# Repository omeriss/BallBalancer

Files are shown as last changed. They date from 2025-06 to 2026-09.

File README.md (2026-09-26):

# Ball-Balancing Platform Firmware

Firmware for an STM32H5 that balances a ball on a tiltable
platform, it is written entirely in C using the native STM32 Ecosystem. A resistive touchscreen is used to sensethe ball's position, a PID
loop turns the position error into a desired platform tilt, an RRS3
parallel-manipulator inverse-kinematics model converts that tilt into three
motor angles, and three stepper motors drive the platform.

## How it works

The main loop in [Core/Src/main.c](Core/Src/main.c) ties everything together:

1. **Sense** — I reads the ball's (x, y) position off
   the resistive touchscreen. Each axis is read by driving one pair of GPIOs
   and sampling the opposing pair through `ADC1`, swapping roles between the
   X and Y axes. Touch calibration is persisted to flash.
2. **Control** — I run the PID controller per axis, in order to get the new desired position.
3. **Inverse kinematics** — [inverse_kinematics.c](User/Src/inverse_kinematics.c)
   solves the RRS3 (Revolute-Revolute-Spherical, 3-leg) parallel manipulator
   geometry, turning a desired platform height + tilt into each
   leg's motor angle.
4. **Actuate** — [stepper.c](User/Src/stepper.c) drives each leg's stepper
   motor via step/direction GPIOs.

Peripheral init (clocks, GPIO, ADC1, TIM1, I2C1) is generated by STM32CubeMX
from [h52.ioc](h52.ioc) into `Core/` and `cmake/stm32cubemx/`. All
application logic lives in `User/Src` / `User/Inc`, wired
together from the `USER CODE` sections of `Core/Src/main.c`.

## Repository layout

```
Core/                  CubeMX-generated HAL init + main.c (USER CODE sections only are hand-edited)
Drivers/               STM32H5 HAL + CMSIS (vendored)
User/Src, User/Inc/    Application logic: screen, pid, inverse_kinematics, stepper, utils
cmake/                 Toolchain file + generated stm32cubemx CMake target
tests/                 Host-side unit tests for inverse_kinematics.c
h52.ioc                CubeMX project file
```

## Parts List

- STM32H503CBT6 microcontroller
- 3x NEMA 16 stepper motors
- 3x TMC2208 stepper drivers
- 8V-100V to 3.3V voltage regulator
- 15V power supply
- 3x 100uF capacitors
- 3x 26mm tie rods
- M3 screws (6x 22mm, 12x 12mm, 5x 10mm)
- Proto PCBs and wires / custom PCB
- 3D printed parts

## Images

<p float="left">
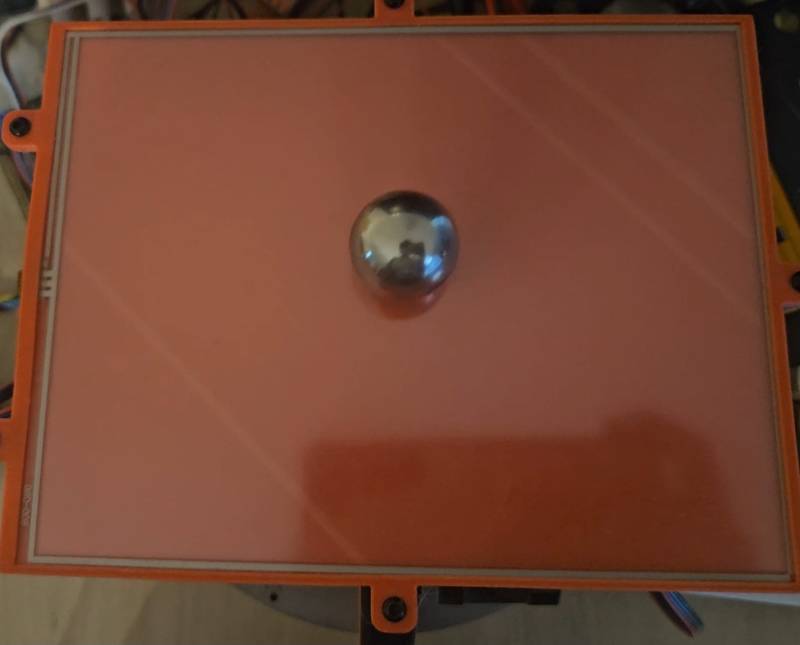
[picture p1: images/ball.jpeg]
Ball
  
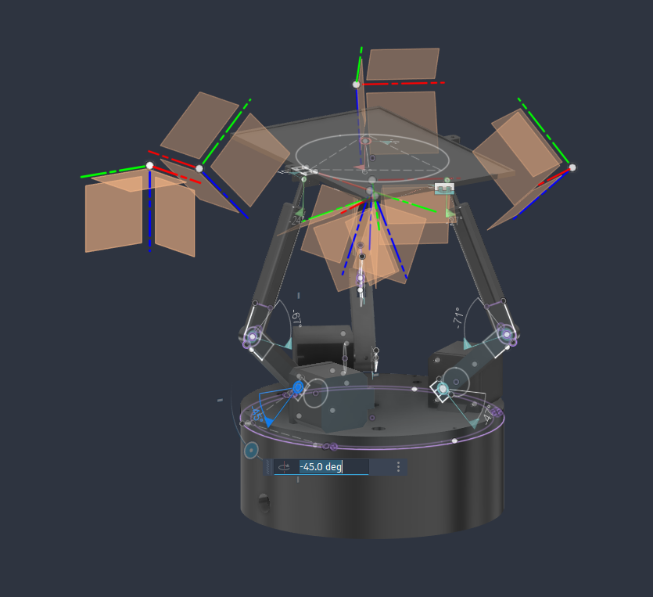
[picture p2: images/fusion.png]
Fusion 360 design
  
</p>

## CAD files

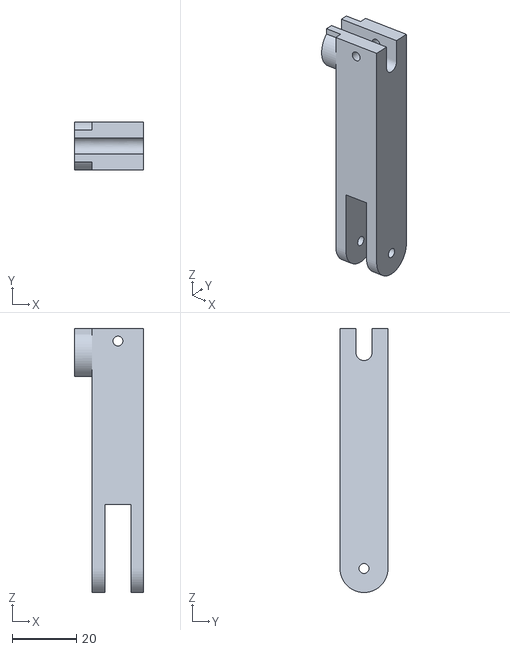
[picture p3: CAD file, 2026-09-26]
3dFiles/leg_buttom.stl
21.7 x 15.0 x 82.5

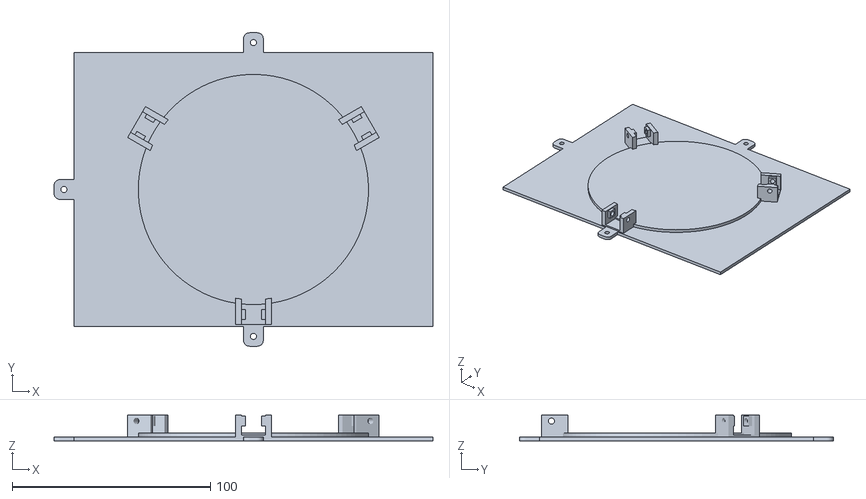
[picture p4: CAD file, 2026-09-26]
3dFiles/screen_bed_buttom.stl
191.0 x 158.0 x 13.0

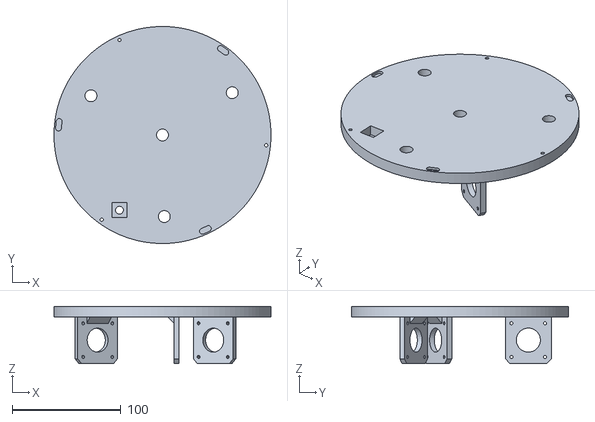
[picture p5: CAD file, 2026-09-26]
3dFiles/base_lid.stl
200.0 x 200.0 x 52.9

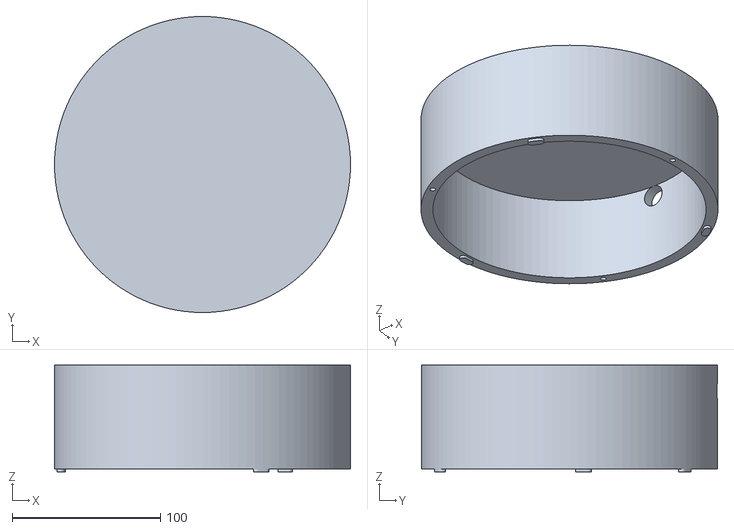
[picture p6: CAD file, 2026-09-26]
3dFiles/base.stl
200.0 x 200.0 x 72.0

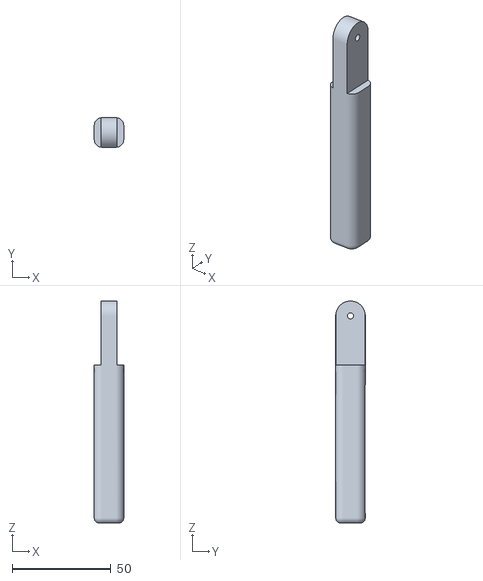
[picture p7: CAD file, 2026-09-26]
3dFiles/leg_top.stl
15.0 x 15.0 x 112.5

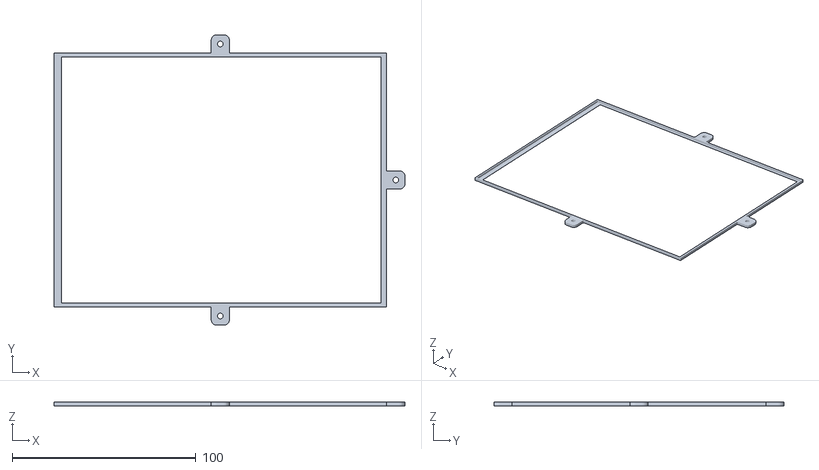
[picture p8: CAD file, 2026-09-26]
3dFiles/screen_bed_lid.stl
191.0 x 158.0 x 2.00

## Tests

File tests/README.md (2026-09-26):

# Inverse Kinematics Unit Tests

This folder contains unit tests for the `inverse_kinematics.c` functions.

## Quick Start

### Option 1: Install TCC (Tiny C Compiler) - Recommended

TCC is the smallest and fastest option to install:

```powershell
winget install tcc
```

Then run:

```powershell
cd tests
.\run_tests.bat
```

### Option 2: Install MinGW (GCC)

```powershell
winget install mingw
```

Then run:

```powershell
cd tests
.\run_tests.bat
```

### Option 3: Use Visual Studio

If you have Visual Studio installed, open "Developer Command Prompt for VS" and run:

```cmd
cd tests
run_tests.bat
```

### Option 4: Direct Compilation

If you have a C compiler in your PATH:

**With GCC/MinGW:**

```powershell
cd tests
gcc -o test_inverse_kinematics.exe test_inverse_kinematics.c -lm
.\test_inverse_kinematics.exe
```

**With MSVC (from Developer Command Prompt):**

```cmd
cd tests
cl /Fe:test_inverse_kinematics.exe test_inverse_kinematics.c
test_inverse_kinematics.exe
```

## Test Coverage

The tests cover:

1. **`rrs3_options_create`**
   - Basic parameter assignment
   - Zero values
   - Negative values (edge case)

2. **`rrs3_calculate_angles`**
   - Level platform (nx=0, ny=0)
   - X-axis tilt
   - Y-axis tilt
   - Varying heights
   - All three legs (A, B, C)
   - Symmetry verification
   - Extreme tilt values
   - Consistency (same input → same output)

## Expected Output

```
==============================================
  Inverse Kinematics Unit Tests
==============================================

--- Running test_rrs3_options_create_basic ---
  [PASS] buttomLeg should be 50.0 (expected: 50.0000, actual: 50.0000)
  [PASS] topLeg should be 100.0 (expected: 100.0000, actual: 100.0000)
  ...

==============================================
  Test Summary
==============================================
  Total:  XX
  Passed: XX
  Failed: 0
==============================================
```

## Adding New Tests

To add new tests:

1. Create a new test function:

```c
void test_my_new_test(void)
{
    // Setup
    RRS3Options options = rrs3_options_create(50.0f, 80.0f, 60.0f, 40.0f);

    // Execute
    float result = rrs3_calculate_angles(A, &options, 100.0f, 0.0f, 0.0f);

    // Assert
    TEST_ASSERT_FLOAT_VALID(result, "Result should be valid");
    TEST_ASSERT_FLOAT_EQ(expected, result, 0.01f, "Result matches expected");
}
```

2. Add it to `main()`:

```c
RUN_TEST(test_my_new_test);
```

## Notes

- Tests run on the **host machine** (Windows/Linux/macOS), not on the STM32 target
- The test file includes a copy of the functions to avoid cross-compilation issues
- If you modify `inverse_kinematics.c`, update the copy in `test_inverse_kinematics.c`

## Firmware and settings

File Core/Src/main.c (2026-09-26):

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
/* Includes ------------------------------------------------------------------*/
#include "main.h"
#include "adc.h"
#include "gpio.h"
#include "i2c.h"
#include "icache.h"
#include "memorymap.h"
#include "tim.h"

/* USER CODE BEGIN PD */
#define MOTOR_ACCELERATION 1000
#define MOTOR_STEPS_PER_REVOLUTION 200
#define MOTOR_MICROSTEPPING 8
#define MOTOR_MAX_STEPS_GAP 9000
#define MOTOR_MIN_STEPS_GAP 3000
#define MOTOR_INITIAL_ANGLE_DEG 90

#define MOTOR1_START_ANGLE_DEG 195
#define MOTOR2_START_ANGLE_DEG 195
#define MOTOR3_START_ANGLE_DEG 195

#define SCREEN_WIDTH_PX 178
#define SCREEN_HEIGHT_PX 136

#define RRS3_BOTTOM_LEG_MM 67.5f
#define RRS3_TOP_LEG_MM 125.5f
#define RRS3_BASE_RADIUS_MM 63.0f
#define RRS3_PLATFORM_RADIUS_MM 63.0f
#define PLATFORM_HEIGHT_MM 150.0f

#define SCREEN_POSITION_SCALE 400.0f

#define PID_KP 0.5f
#define PID_KI 0.015f
#define PID_KD 0.25f
#define PID_INTEGRAL_LIMIT 0.015f
#define PID_OUTPUT_LIMIT 0.1f
/* USER CODE END PD */


void SystemClock_Config(void);
/**
 * @brief  The application entry point.
 * @retval int
 */
int main(void) {

  /* MCU Configuration--------------------------------------------------------*/

  /* Reset of all peripherals, Initializes the Flash interface and the Systick.
   */
  HAL_Init();

  /* Configure the system clock */
  SystemClock_Config();

  /* Initialize all configured peripherals */
  MX_GPIO_Init();
  MX_ICACHE_Init();
  MX_TIM1_Init();
  MX_ADC1_Init();
  MX_I2C1_Init();
  /* USER CODE BEGIN 2 */

  // if (!MPU_begin(&hi2c1, AD0_LOW, AFSR_4G, GFSR_500DPS, 0.98, 0.004))
  // {
  //   while (1)
  //   {
  //     HAL_Delay(100);
  //   }
  // }

  // while (true)
  // {
  //   MPU_calcAttitude(&hi2c1);
  // }

  HAL_GPIO_WritePin(GPIOA, GPIO_PIN_11, GPIO_PIN_SET);
  // read timer value
  HAL_TIM_Base_Start(&htim1); // Start the timer
  StepperMotorConfig motorConfig = {.acceleration = MOTOR_ACCELERATION,
                                    .stepsPerRevolution = MOTOR_STEPS_PER_REVOLUTION,
                                    .microstepping = MOTOR_MICROSTEPPING,
                                    .timerHandle = &htim1,
                                    .maxStepsGap = MOTOR_MAX_STEPS_GAP,
                                    .minStepsGap = MOTOR_MIN_STEPS_GAP};

  StepperMotor motor1 = motor_create(&motorConfig, GPIOB, GPIO_PIN_15,
                                     GPIO_PIN_14, MOTOR1_START_ANGLE_DEG, true);
  StepperMotor motor2 = motor_create(&motorConfig, GPIOA, GPIO_PIN_9,
                                     GPIO_PIN_8, MOTOR2_START_ANGLE_DEG, true);
  StepperMotor motor3 = motor_create(&motorConfig, GPIOA, GPIO_PIN_11,
                                     GPIO_PIN_10, MOTOR3_START_ANGLE_DEG, true);
  Screen screen = screen_create(
      SCREEN_WIDTH_PX, SCREEN_HEIGHT_PX, &htim1, GPIOA, GPIO_PIN_2, GPIOA,
      GPIO_PIN_3, GPIOA, GPIO_PIN_0, GPIOA, GPIO_PIN_1, &hadc1,
      ADC_CHANNEL_14, ADC_CHANNEL_0);

  // screen_calibration(&screen);
  screen_load_calibration(&screen);
  RRS3Options rrs3Options = {.buttomLeg = RRS3_BOTTOM_LEG_MM,
                             .topLeg = RRS3_TOP_LEG_MM,
                             .baseR = RRS3_BASE_RADIUS_MM,
                             .platformR = RRS3_PLATFORM_RADIUS_MM};

  PIDConfig pidConfig = {.kp = PID_KP,
                         .ki = PID_KI,
                         .kd = PID_KD,
                         .integralLimit = PID_INTEGRAL_LIMIT,
                         .outputLimit = PID_OUTPUT_LIMIT};
  PID pidX = pid_create(&pidConfig);
  PID pidY = pid_create(&pidConfig);
  uint32_t lastTime = HAL_GetTick();

  motor_set_angle(&motor1, MOTOR_INITIAL_ANGLE_DEG);
  motor_set_angle(&motor2, MOTOR_INITIAL_ANGLE_DEG);
  motor_set_angle(&motor3, MOTOR_INITIAL_ANGLE_DEG);
  /* USER CODE END 2 */

  /* Infinite loop */
  /* USER CODE BEGIN WHILE */
  while (1) {
    ScreenData screenData = screen_read(&screen);

    float x = (screenData.x - screen.width / 2) / SCREEN_POSITION_SCALE;
    float y = -1 * (screenData.y - screen.height / 2) / SCREEN_POSITION_SCALE;

    float dt = pid_compute_dt(&lastTime);

    float newX = pid_update(&pidX, x, dt);
    float newY = pid_update(&pidY, y, dt);

    float angleA = rrs3_calculate_angles(A, &rrs3Options, PLATFORM_HEIGHT_MM,
                                         newX, newY);
    float angleB = rrs3_calculate_angles(B, &rrs3Options, PLATFORM_HEIGHT_MM,
                                         newX, newY);
    float angleC = rrs3_calculate_angles(C, &rrs3Options, PLATFORM_HEIGHT_MM,
                                         newX, newY);

    motor_set_angle(&motor1, angleA);
    motor_set_angle(&motor2, angleB);
    motor_set_angle(&motor3, angleC);

    motor_run(&motor1);
    motor_run(&motor2);
    motor_run(&motor3);
    /* USER CODE END WHILE */

    /* USER CODE BEGIN 3 */
  }
  /* USER CODE END 3 */
}

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


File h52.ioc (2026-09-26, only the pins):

Mcu.UserName=STM32H503CBTx
PA0.Signal=ADCx_INP0
PA1.Signal=GPIO_Output
PA10.Signal=GPIO_Output
PA11.Signal=GPIO_Output
PA2.Signal=ADCx_INP14
PA3.Signal=GPIO_Output
PA8.Signal=GPIO_Output
PA9.Signal=GPIO_Output
PB12.Signal=GPIO_Output
PB14.Signal=GPIO_Output
PB15.Signal=GPIO_Output
PB5.Signal=GPIO_Input
PB6.Signal=I2C1_SCL
PB7.Signal=I2C1_SDA
PC13.Signal=GPIO_Output

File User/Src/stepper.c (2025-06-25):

#include "stepper.h"

uint16_t getAngleStep(const StepperMotorConfig *config, float angle)
{
    return (uint16_t)(angle / (360.0f / config->stepsPerRevolution)) * config->microstepping;
}

StepperMotor motor_create(StepperMotorConfig *config, GPIO_TypeDef *port, uint16_t stepPin, uint16_t dirPin, uint8_t startAngle, bool reverse)
{
    uint16_t initialStep = getAngleStep(config, startAngle);
    HAL_GPIO_WritePin(port, stepPin, GPIO_PIN_RESET);
    HAL_GPIO_WritePin(port, dirPin, GPIO_PIN_RESET);

    return (StepperMotor){
        .port = port,
        .stepPin = stepPin,
        .dirPin = dirPin,
        .config = *config,
        .speed = 0,
        .step = initialStep,
        .desiredStep = initialStep,
        .reverse = reverse,
        .stepPinState = false,
        .lastDirState = reverse,
    };
}

void motor_set_angle(StepperMotor *motor, float angle)
{
    if (angle < 0 || angle >= 360)
        return;

    motor->desiredStep = getAngleStep(&motor->config, angle);
}

void motor_run(StepperMotor *motor)
{
    // make step Gap largger the bigger the difference between desired and current step
    uint16_t stepDiff = motor->desiredStep > motor->step
                            ? motor->desiredStep - motor->step
                            : motor->step - motor->desiredStep;

    uint16_t stepTime = motor->config.maxStepsGap - (MIN(MAX_ANGLE_DIFF, stepDiff) * (motor->config.maxStepsGap - motor->config.minStepsGap) / MAX_ANGLE_DIFF);

    if (motor->desiredStep == motor->step)
        return;

    uint16_t time = __HAL_TIM_GET_COUNTER(motor->config.timerHandle);
    uint16_t timeDiff = (uint16_t)(time - motor->lastRunTime);
    timeDiff += motor->lastRunRemainder;

    if (timeDiff < stepTime)
        return;

    motor->lastRunTime = time;
    motor->lastRunRemainder = MAX(timeDiff - stepTime, MAX_REMAINDER);

    bool dir = (motor->desiredStep > motor->step);

    if (motor->lastDirState != dir)
    {
        motor->lastDirState = dir;
        HAL_GPIO_WritePin(motor->port, motor->dirPin, (dir ^ motor->reverse));

        if (!motor->stepPinState)
            return;
    }

    HAL_GPIO_WritePin(motor->port, motor->stepPin, !motor->stepPinState);
    motor->step += (dir * 2 - 1) * (!motor->stepPinState);
    motor->stepPinState = !motor->stepPinState;
}

bool motor_is_in_position(StepperMotor *motor)
{
    return motor->desiredStep == motor->step;
}

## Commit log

2026-06-27 feat: split pid from main
2026-06-27 feat: add 3d files
    [base.stl, base_lid.stl, leg_buttom.stl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]

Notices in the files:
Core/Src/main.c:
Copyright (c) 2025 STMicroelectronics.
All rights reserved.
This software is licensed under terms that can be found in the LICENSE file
